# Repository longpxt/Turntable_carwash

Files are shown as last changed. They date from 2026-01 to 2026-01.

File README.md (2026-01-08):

infinity
model

# Turntable Car Wash (aka “Tron Car Wash”)

An open-hardware, industrial-scale in-bay car wash architecture that replaces the traditional moving overhead gantry with a **servo-driven turntable** and **parallel Spray Column modules**.

> Goal: increase throughput, simplify hose/cable routing, and improve maintainability by “inverting” the conventional in-bay design.

---
## OSHWA Certification

This project is **OSHWA Open Source Hardware Certified**.

- **OSHWA Certification ID:** **VN000001**
- Certification page: https://certification.oshwa.org/vn000001.html

---
## Context and motivation

Most in-bay automatic car washes rely on an overhead gantry that moves back-and-forth along the vehicle. While widely adopted, this approach tends to increase mechanical complexity and adds stress to **hose routing** and **cable management** due to constant motion and repeated travel paths.

This project explores a different architecture aimed at:
- reducing moving-axis complexity,
- enabling easier maintenance and modular expansion,
- improving process parallelism (multiple wash actions at once).

---

## The inverted architecture

**Turntable Car Wash** reverses the common approach:

- The **vehicle rotates** on a servo-driven turntable (angle-accurate rotation).
- The washing hardware is organized as **stationary modules** (Spray Columns) around the vehicle.
- By eliminating the moving gantry, **hose/cable runs can be shorter**, less twisted, and easier to service.

---

## Parallel washing modules (Spray Columns)

With the gantry eliminated, multiple **Spray Column** modules can work in parallel:
- Pre-soak, wash, rinse, wax, and spot-free can be distributed across modules.
- The system can reduce reliance on repeated serial gantry passes.
- Control logic focuses on *orchestrating parallel actions* and optimizing rotation timing.

---

## System structure

Key subsystems include:
- **Servo-driven turntable** for smooth, angle-accurate rotation
- **Spray Column modules** (modular washing columns)
- **PLC control** for deterministic motion + sequencing
- **Embedded PC software** 
- **Electrical system** integrating PLC, servo drive(s), pumps and sensors.
- **Industrial mechanical structure** designed for replication and serviceability (sheet metal/bolted assemblies)

---

## Repository layout

├─ Spray column/
│ └─ SolidWorks design files for the washing module (Spray Column)
├─ Turntable/
│ └─ SolidWorks design files for the servo-driven turntable
├─ Software & PLC/
│ ├─ PLC source code (control logic, sequencing, motion)
│ └─ Embedded PC software source code 
└─ Electrical/
└─ Electrical drawings for PLC, servo, pumps, and overall control system

---

## Prototype status and early observations

An MVP prototype with a single wash module has been built and tested. Early observations indicate that:
- The architecture is feasible for in-bay operation.
- Optimization of rotation + spray timing has a measurable impact on wash quality and resource usage.
- Long-term reliability will depend heavily on the turntable subsystem design (sealing, drainage, and protection in wet/chemical environments).

---

## Known engineering challenges / trade-offs

The **turntable** is the most demanding subsystem, with challenges including:
- long-life bearings and sealing in a wet, chemical environment,
- debris / grit intrusion protection,
- drainage and corrosion mitigation,
- mechanical rigidity under vehicle load,
- safety interlocks and fault handling for rotating machinery.

---

## Demonstration

Video demo: https://youtu.be/eL5WlzASyZ8

---

## Open release

This project is released as **open hardware** under the **CERN Open Hardware Licence (CERN-OHL-W)**.

- Hardware files: CAD (SolidWorks), electrical drawings
- Control: PLC code
- Software: embedded PC components

See the `LICENSE` file for the exact terms.

---

## Safety notice

This is an **industrial machine concept** involving electricity, rotating machinery, pressurized water, and chemicals.
You are responsible for ensuring compliance with local electrical/mechanical codes, safety guarding, E-stop strategy, interlocks, and chemical handling requirements before building or operating any derivative system.

---

## Contributing

Contributions are welcome:
- mechanical design improvements (turntable sealing/drainage, modularization)
- PLC sequencing and safety logic
- embedded software
- documentation (assembly, commissioning, maintenance)

---

## Author

**Long Phan** — inventor and R&D contractor working across mechanical design, automation, software, and IoT.
For questions, please contact: **longphan@ieee.org**

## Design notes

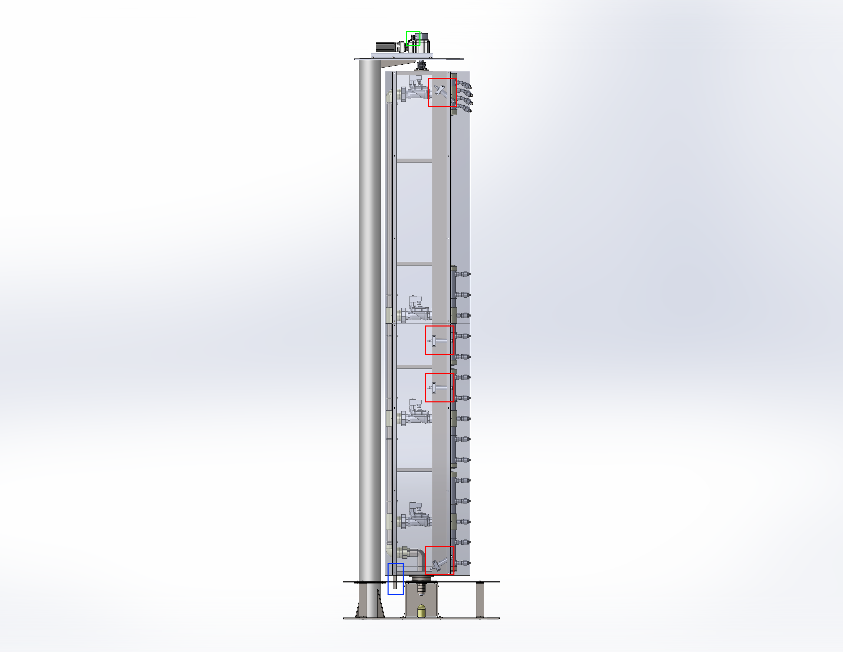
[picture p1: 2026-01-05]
Spray column/Images/2a.png

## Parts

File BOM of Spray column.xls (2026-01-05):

ITEM NO. | PART NUMBER | DESCRIPTION | QTY.
1 | C-pillar base mount |  | 1
2 | DN125 column |  | 1
3 | U-bracket rotary joint base |  | 1
4 | 22212 bearing flange |  | 1
5 | SKF_22212 E_ir_oh |  | 1
6 | SKF_22212 E_or_oh |  | 1
7 | SKF_22212 E_r1_oh |  | 19
8 | SKF_22212 E_r2_oh |  | 19
9 | 22212 bearing bottom flange |  | 1
10 | U-bracket rotary joint base cover |  | 2
11 | base reinforcement plate |  | 4
12 | upper spray-column alignment bar |  | 1
13 | gearbox-mount reinforcement |  | 1
14 | ground-cover base bracket |  | 5
15 | reinforced ground- cover base bracket |  | 5
16 | round-post ground- cover base bracket |  | 1
17 | ground surface cover |  | 1
18 | ground surface cover – right |  | 1
19 | Z22H gearbox support bracket |  | 1
20 | AFCZ22S_50M200S2_No ne__3_oh |  | 1
21 | AFCZ22S_50M200S2_No ne__5_oh |  | 1
22 | servo SGMAH- 04AAA41_vthtp3_oh | Yaskawa SGMAH- 04AAA41 or Mitsubishi MR-J3-40A | 1
23 | Z22 gearbox shaft |  | 1
24 | bowex_m24_1b |  | 1
25 | bowex_m24_3b |  | 1
26 | bowex_m24_2b |  | 1
27 | limit-switch jig |  | 1
28 | Z22 limit-switch shaft |  | 1
29 | V_155_1A5_BASE |  | 3
30 | V_155_1A5_ACTUATOR |  | 3
31 | DIN 912 M4 x 10 --- 10N |  | 4
32 | DIN 912 M6 x 10 --- 10N |  | 1
33 | DIN 912 M8 x 12 --- 12N |  | 10
34 | JIS B 1111 Binding head screw M3 x 35 -- 12N |  | 2
35 | DIN 912 M5 x 16 --- 16N |  | 36
36 | solenoid_valve_1b_3b_ oh |  | 4
37 | solenoid_valve_2b_3b_ 3b_oh |  | 4
38 | solenoid_valve_3b_3b_ 3b_oh |  | 4
39 | DN50 PPR water distribution pipe |  | 1
40 | DN50 PPR male-thread union |  | 8
41 | DN40-PN25 threaded flange |  | 2
42 | DN50 PPR tee |  | 7
43 | DN50 PPR female- thread straight connector |  | 1
44 | DN50 PPR elbow |  | 2
45 | DN50 PPR distributor pipe |  | 3
46 | DN50 PPR end cap |  | 8
47 | PPR weld in saddle 50–20 |  | 14
48 | PPR weld in saddle 75–20 |  | 5
49 | DN50 PPR coupling–distributor joint |  | 4
50 | Female Thread Reducer DN15-DN8 |  | 19
51 | PPR Female threaded coupling 20xDN15 |  | 15
52 | Spay MEG 1530 |  | 19
53 | upper DN50 PPR distributor |  | 1
54 | PPR Female threaded coupling 20xDN15 45deg |  | 4
55 | HD40R bod |  | 1
56 | HD40R base v3-3b |  | 1
57 | water supply pipe |  | 1
58 | DN40 male-female thread adapter |  | 1
59 | spray-pipe housing – base |  | 1
60 | spray-pipe housing – rear panel |  | 1
61 | spray-pipe housing – front panel |  | 1
62 | spray-pipe housing – cross bar |  | 4
63 | spray-pipe housing – cover |  | 1
64 | spray-pipe housing – pipe clamp |  | 8
65 | Top flange |  | 1
66 | foam-nozzle hose clamp |  | 1
67 | spray-pipe housing – main-nozzle locator |  | 1
68 | DIN 912 M8 x 20 --- 20N |  | 4
69 | DIN EN ISO 10511 - M8 - N |  | 4
70 | rear lower side cover |  | 1
71 | rear upper side cover |  | 1
72 | front lower side cover - left |  | 1
73 | front upper side cover - left |  | 1
74 | rear lower side cover - left |  | 1
75 | rear upper side cover - left |  | 1
76 | front lower side cover |  | 1
77 | front upper side cover |  | 1
78 | foam nozzle |  | 4
79 | foam-nozzle clamp |  | 8
80 | DIN 912 M6 x 50 --- 24N |  | 8
81 | DIN EN ISO 10511 - M6 - N |  | 8
82 | U bold |  | 7
83 | water-spray pipe cover – rear |  | 2
84 | water-spray pipe cover – side |  | 4
85 | water-spray pipe cover – front-upper (reversed) |  | 1
86 | water-spray pipe cover – front-lower (reversed) |  | 1
87 | front water-spray pipe jig |  | 1
88 | upper front water- spray pipe jig |  | 1

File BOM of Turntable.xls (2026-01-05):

ITEM NO. | PART NUMBER | DESCRIPTION | QTY.
1 | base support |  | 1
2 | upper bearing retainer ring |  | 1
3 | rotary hub cover |  | 1
4 | shaft of center hub |  | 1
5 | brass bushing 110 |  | 1
6 | 51224_bottom |  | 1
7 | 51224_middle |  | 1
8 | 51224_top |  | 1
9 | turntable flange plate |  | 1
10 | outer running track 60 |  | 6
11 | center-track connecting bar |  | 6
12 | inner running track 60 |  | 6
13 | inner-track connecting bar |  | 6
14 | linkage |  | 60
15 | ram base |  | 16
16 | top ram plate |  | 16
17 | ram support |  | 80
18 | upper cover plate center |  | 1
19 | 50-1 cross bar |  | 16
20 | 50-2 cross bar |  | 16
21 | distribution-bar 50x50 |  | 16
22 | PU51x17 |  | 32
23 | SKF 6003 |  | 64
24 | shaft 17x134 |  | 32
25 | wheel frame PU51x17 |  | 32
26 | turntable distribution- bar linkage |  | 16
27 | distribution-bar cover |  | 16
28 | M5-54 rack strip liner |  | 32
29 | 50-31 cross bar |  | 16
30 | 50-41 cross bar |  | 16
31 | support bar |  | 16
32 | M5-54 strip |  | 16
33 | bottom triangle linkage |  | 8
34 | top triangle linkage |  | 8
35 | triangle cover plate |  | 1
36 | WS120F grearbox | GTC | 1
37 | HC SFS 152 | Mitsubishi | 1
38 | gearbox gear |  | 1
39 | gearbox base |  | 1
40 | servo shaft 24 |  | 1
41 | gearbox housing |  | 1

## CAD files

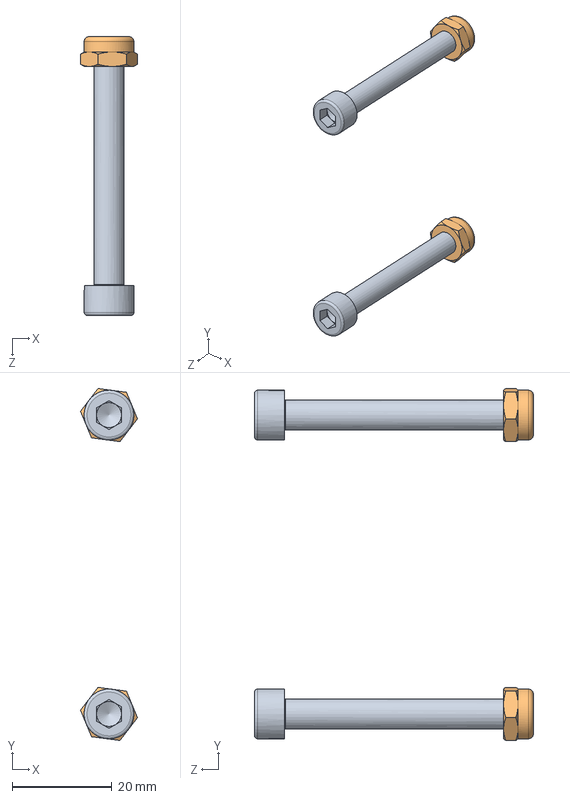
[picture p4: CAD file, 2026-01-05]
Spray column/Foam Nozzle Cluster Assembly.SLDASM
11.4 x 70.7 x 56.0 mm
socket head cap screw_din x 2
prevailing torque nut thin insert_din x 2

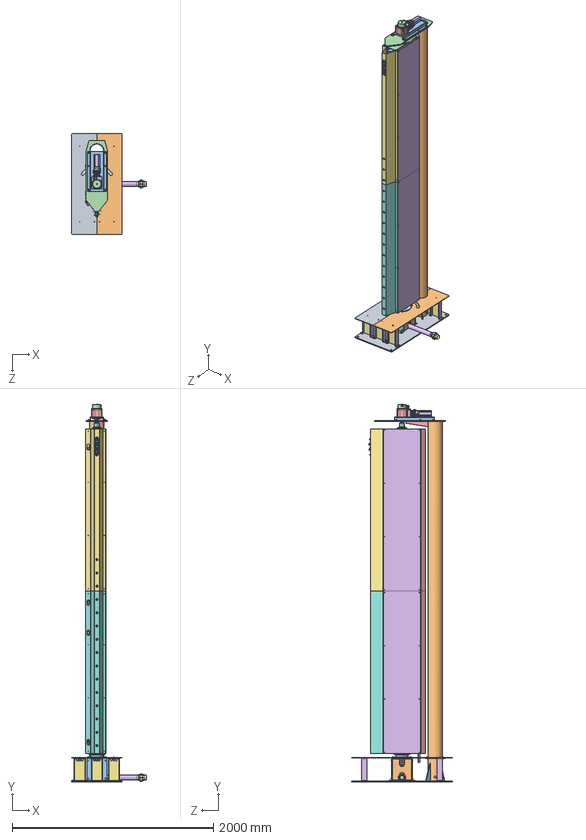
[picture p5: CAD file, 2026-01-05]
Spray column/Spray Column Assem.SLDASM
741.2 x 3755.0 x 1000.0 mm
C-pillar base mount
DN125 column
U-bracket rotary joint base
22212 bearing flange
SKF_22212 E_ir_oh
SKF_22212 E_or_oh
SKF_22212 E_r1_oh x 19
SKF_22212 E_r2_oh x 19
22212 bearing bottom flange
U-bracket rotary joint base cover x 2
base reinforcement plate x 4
upper spray-column alignment bar
gearbox-mount reinforcement
ground-cover base bracket x 5
reinforced ground-cover base bracket x 5
round-post ground-cover base bracket
ground surface cover
ground surface cover – right
Z22H gearbox support bracket
AFCZ22S_50M200S2_None__3_oh
AFCZ22S_50M200S2_None__5_oh
servo SGMAH-04AAA41_vthtp3_oh
Z22 gearbox shaft
bowex_m24_1b
bowex_m24_3b
bowex_m24_2b
limit-switch jig
Z22 limit-switch shaft
V_155_1A5_BASE x 3
V_155_1A5_ACTUATOR x 3
socket head cap screw_din x 63
cross recessed binding head screw_jis x 2
solenoid_valve_1b_3b_oh x 4
solenoid_valve_2b_3b_3b_oh x 4
solenoid_valve_3b_3b_3b_oh x 4
DN50 PPR water distribution pipe
DN50 PPR male-thread union x 8
DN40-PN25 threaded flange x 2
DN50 PPR tee x 7
DN50 PPR female-thread straight connector
DN50 PPR elbow x 2
DN50 PPR distributor pipe x 3
DN50 PPR end cap x 8
PPR weld in saddle 50–20 x 14
PPR weld in saddle 75–20 x 5
DN50 PPR coupling–distributor joint x 4
Female Thread Reducer DN15-DN8 x 19
PPR Female threaded coupling 20xDN15 x 15
Spay MEG 1530 x 19
upper DN50 PPR distributor
PPR Female threaded coupling 20xDN15 45deg x 4
HD40R bod
HD40R base v3-3b
water supply pipe
DN40 male-female thread adapter
spray-pipe housing – base
spray-pipe housing – rear panel
spray-pipe housing – front panel
spray-pipe housing – cross bar x 4
spray-pipe housing – cover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

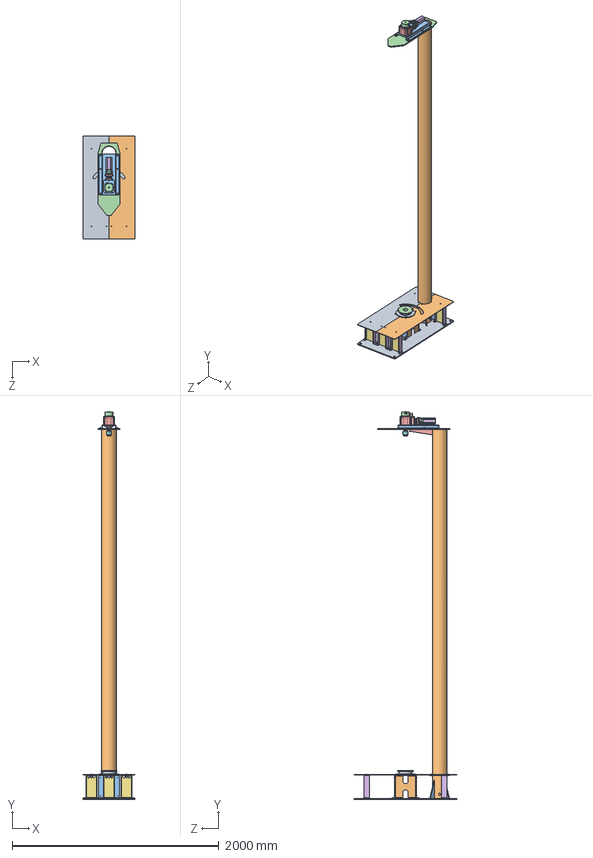
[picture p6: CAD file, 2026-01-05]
Spray column/C-Frame Base Assembly.SLDASM
500.0 x 3755.0 x 1000.0 mm
C-pillar base mount
DN125 column
U-bracket rotary joint base
22212 bearing flange
SKF_22212 E_ir_oh
SKF_22212 E_or_oh
SKF_22212 E_r1_oh x 19
SKF_22212 E_r2_oh x 19
22212 bearing bottom flange
U-bracket rotary joint base cover x 2
base reinforcement plate x 4
upper spray-column alignment bar
gearbox-mount reinforcement
ground-cover base bracket x 5
reinforced ground-cover base bracket x 5
round-post ground-cover base bracket
ground surface cover
ground surface cover – right
Z22H gearbox support bracket
AFCZ22S_50M200S2_None__3_oh
AFCZ22S_50M200S2_None__5_oh
servo SGMAH-04AAA41_vthtp3_oh
Z22 gearbox shaft
bowex_m24_1b
bowex_m24_3b
bowex_m24_2b
limit-switch jig
Z22 limit-switch shaft
socket head cap screw_din x 51
cross recessed binding head screw_jis x 2

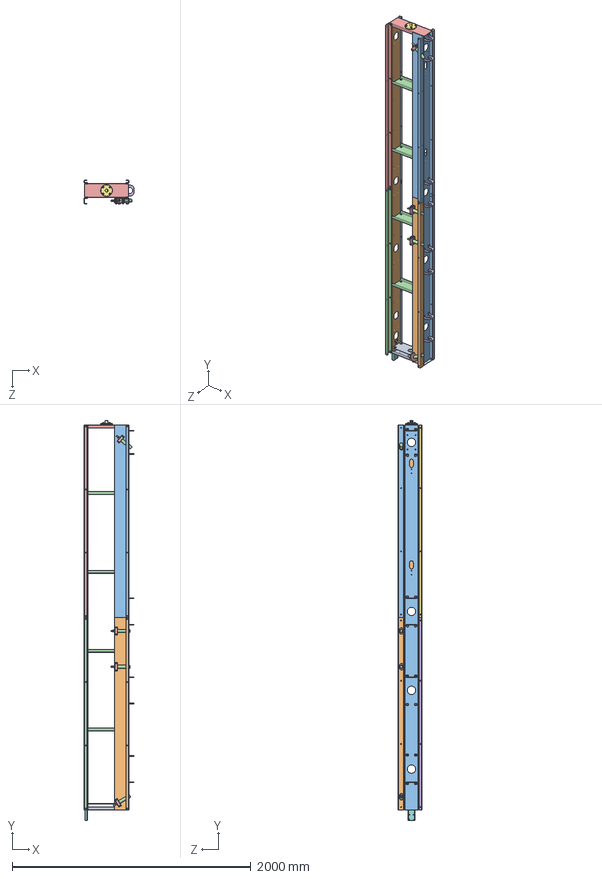
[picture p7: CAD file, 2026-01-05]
Spray column/Spray-Pipe Housing Assembly.SLDASM
417.0 x 3349.0 x 198.0 mm
spray-pipe housing – base
spray-pipe housing – rear panel
spray-pipe housing – front panel
spray-pipe housing – cross bar x 4
spray-pipe housing – cover
spray-pipe housing – pipe clamp x 8
Top flange
foam-nozzle hose clamp
spray-pipe housing – main-nozzle locator
socket head cap screw_din x 12
prevailing torque nut thin insert_din x 12
rear lower side cover
rear upper side cover
front lower side cover - left
front upper side cover - left
rear lower side cover - left
rear upper side cover - left
front lower side cover
front upper side cover
foam nozzle x 4
foam-nozzle clamp x 8

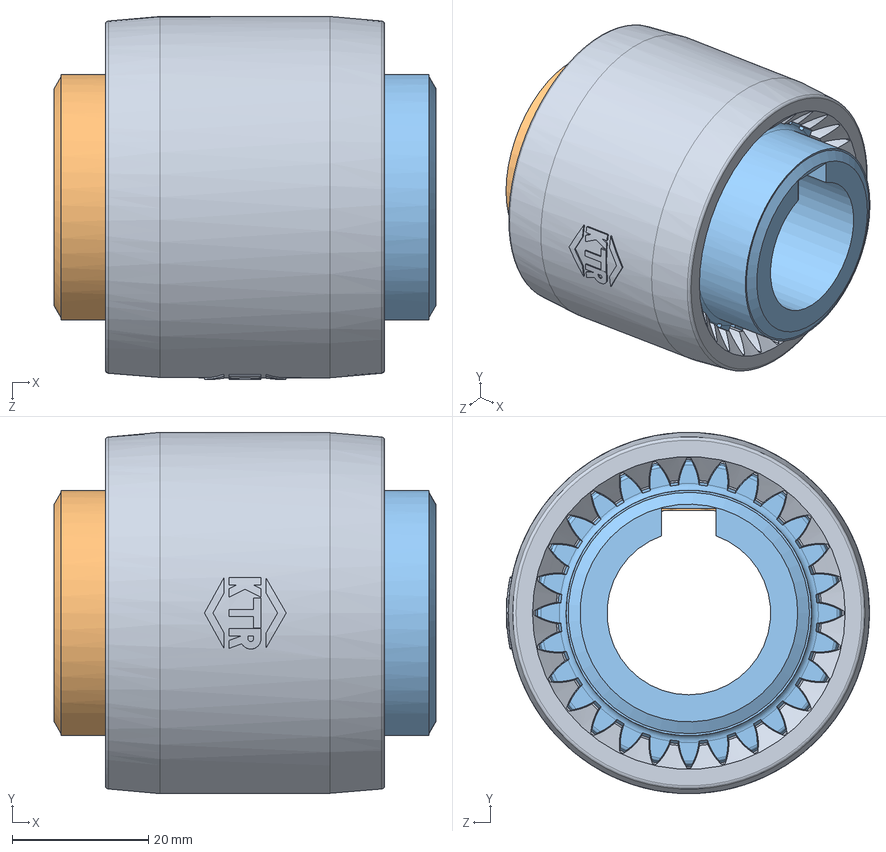
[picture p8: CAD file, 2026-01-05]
Spray column/bowex_m-24_c.SLDASM
56.0 x 53.0 x 53.2 mm
bowex_m24_1b
bowex_m24_3b
bowex_m24_2b

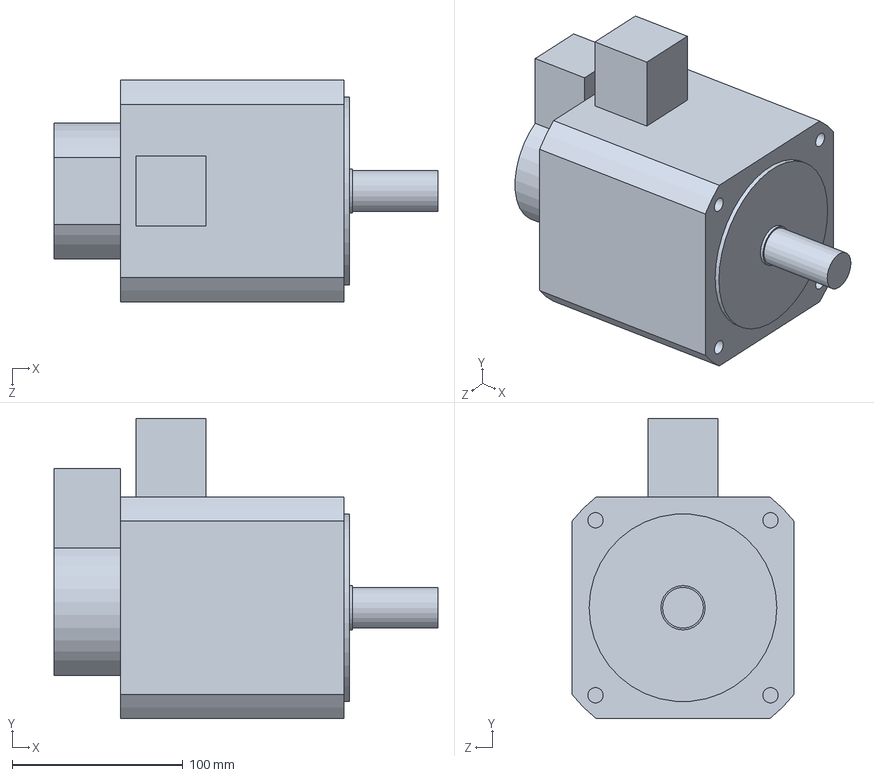
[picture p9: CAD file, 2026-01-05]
Turntable/assem WS120F - HC SFS152.SLDASM
225.0 x 176.0 x 130.0 mm

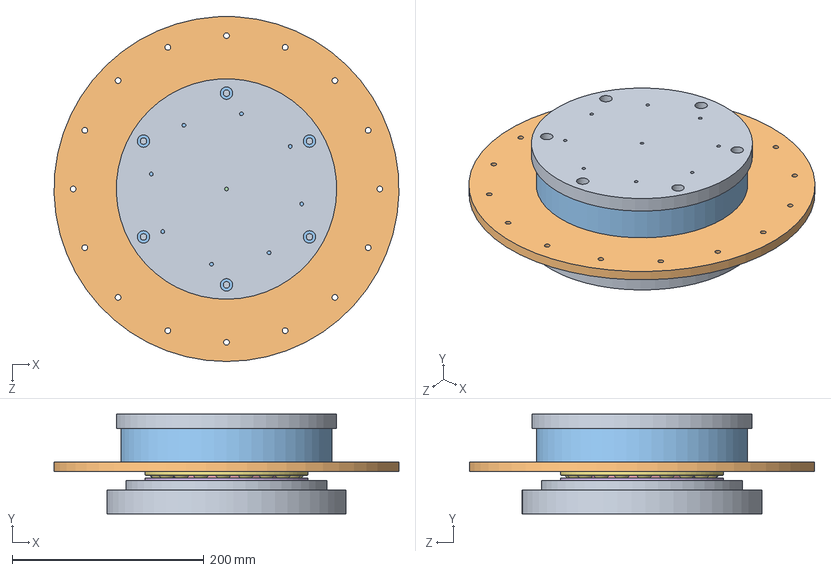
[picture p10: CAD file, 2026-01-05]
Turntable/assem center hub.SLDASM
359.8 x 104.0 x 360.0 mm
base support
upper bearing retainer ring
rotary hub cover
shaft of center hub
brass bushing 110
51224_bottom
51224_middle
51224_top

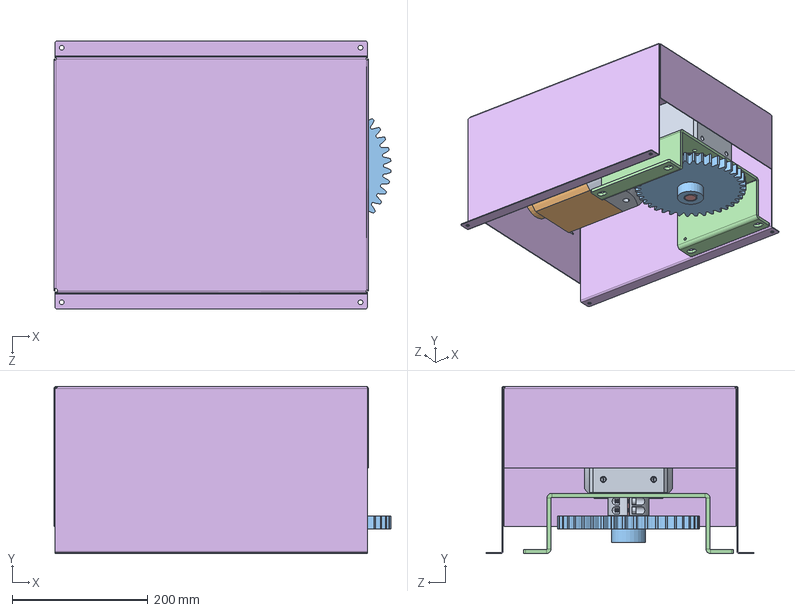
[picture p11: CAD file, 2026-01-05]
Turntable/assem gearbox.SLDASM
496.4 x 246.5 x 395.0 mm
WS120F grearbox
HC SFS 152
gearbox gear
gearbox base
servo shaft 24
gearbox housing

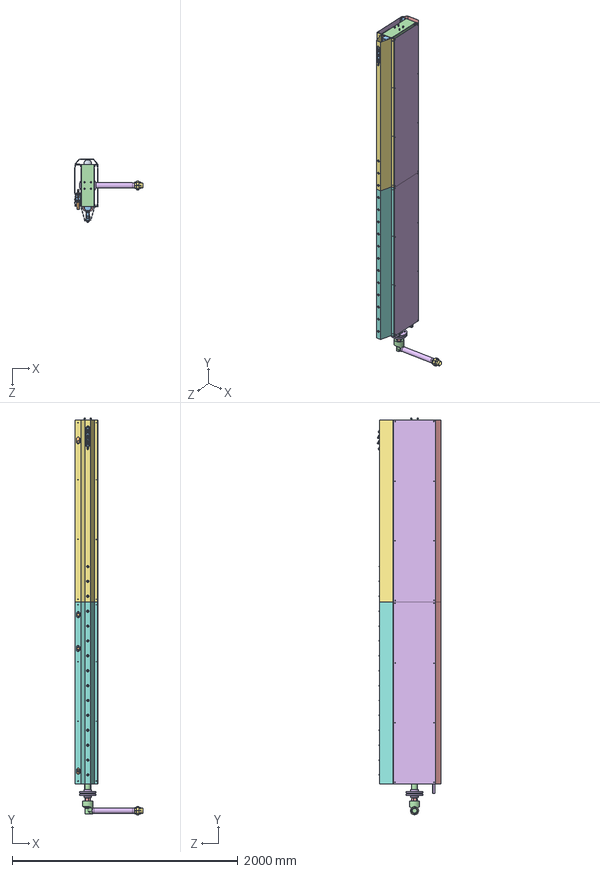
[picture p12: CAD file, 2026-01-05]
Spray column/Water Spray Pipe Assembly.SLDASM
606.2 x 3520.3 x 566.1 mm
solenoid_valve_1b_3b_oh x 4
solenoid_valve_2b_3b_3b_oh x 4
solenoid_valve_3b_3b_3b_oh x 4
DN50 PPR water distribution pipe
DN50 PPR male-thread union x 8
DN40-PN25 threaded flange x 2
DN50 PPR tee x 7
DN50 PPR female-thread straight connector
DN50 PPR elbow x 2
DN50 PPR distributor pipe x 3
DN50 PPR end cap x 8
PPR weld in saddle 50–20 x 14
PPR weld in saddle 75–20 x 5
DN50 PPR coupling–distributor joint x 4
Female Thread Reducer DN15-DN8 x 19
PPR Female threaded coupling 20xDN15 x 15
Spay MEG 1530 x 19
upper DN50 PPR distributor
PPR Female threaded coupling 20xDN15 45deg x 4
HD40R bod
HD40R base v3-3b
water supply pipe
DN40 male-female thread adapter
spray-pipe housing – base
spray-pipe housing – rear panel
spray-pipe housing – front panel
spray-pipe housing – cross bar x 4
spray-pipe housing – cover
spray-pipe housing – pipe clamp x 8
foam-nozzle hose clamp
spray-pipe housing – main-nozzle locator
socket head cap screw_din x 12
prevailing torque nut thin insert_din x 12
rear lower side cover
rear upper side cover
front lower side cover - left
front upper side cover - left
rear lower side cover - left
rear upper side cover - left
front lower side cover
front upper side cover
foam nozzle x 4
foam-nozzle clamp x 8
U bold x 7
water-spray pipe cover – rear x 2
water-spray pipe cover – side x 4
water-spray pipe cover – front-upper (reversed)
water-spray pipe cover – front-lower (reversed)

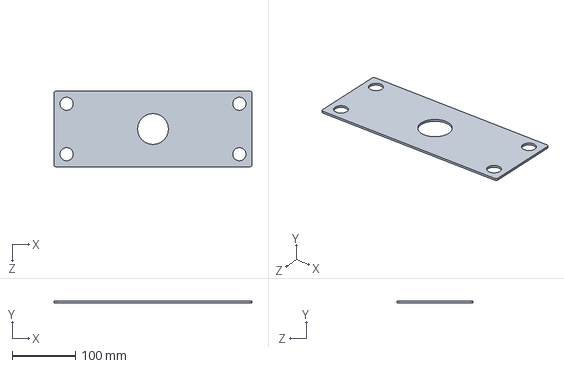
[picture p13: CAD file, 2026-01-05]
Spray column/spray-pipe housing – main-nozzle locator.SLDPRT
314.0 x 3.00 x 120.0 mm

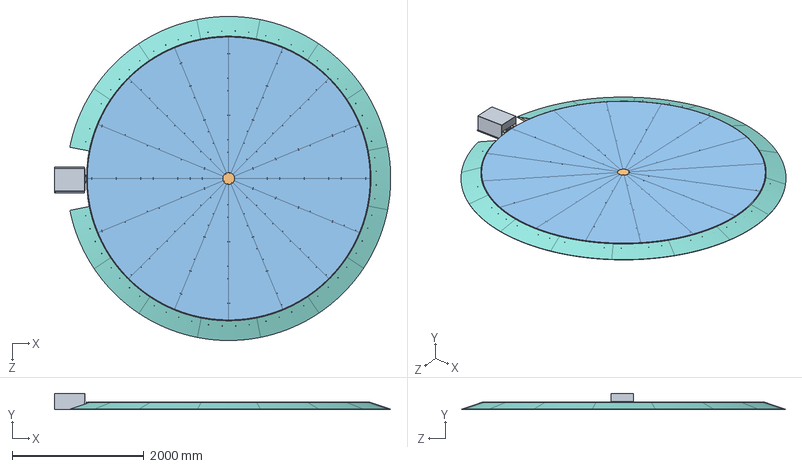
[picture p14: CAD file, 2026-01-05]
Turntable/Assem Turntable.SLDASM
5113.6 x 246.5 x 4924.9 mm
base support
upper bearing retainer ring
rotary hub cover
shaft of center hub
brass bushing 110
51224_bottom
51224_middle
51224_top
turntable flange plate
outer running track 60 x 6
center-track connecting bar x 6
inner running track 60 x 6
inner-track connecting bar x 6
linkage x 60
ram base x 15
top ram plate x 15
ram support x 75
upper cover plate center
50-1 cross bar x 16
50-2 cross bar x 16
distribution-bar 50x50 x 16
PU51x17 x 32
SKF 6003 x 64
shaft 17x134 x 32
wheel frame PU51x17 x 32
turntable distribution-bar linkage x 16
distribution-bar cover x 16
M5-54 rack strip liner x 32
50-31 cross bar x 16
50-41 cross bar x 16
support bar x 16
M5-54 strip x 16
bottom triangle linkage x 8
top triangle linkage x 8
triangle cover plate x 16
WS120F grearbox
HC SFS 152
gearbox gear
gearbox base
servo shaft 24
gearbox housing

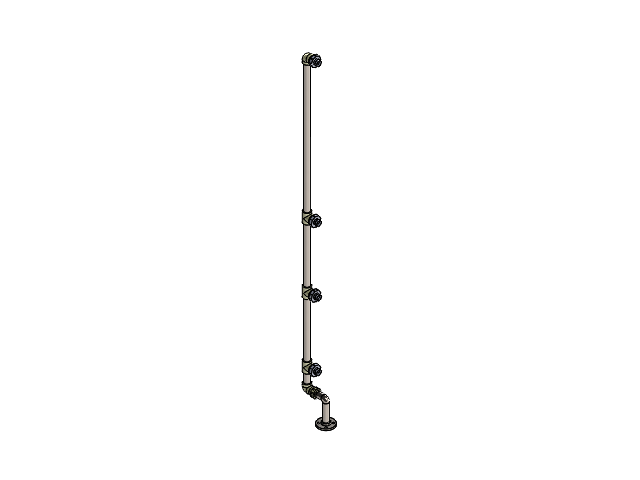
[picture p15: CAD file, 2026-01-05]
Spray column/DN40 Stainless-Steel Water Distributor Assembly.SLDASM
DN50 PPR water distribution pipe
DN50 PPR male-thread union x 4
DN40-PN25 threaded flange
DN50 PPR tee x 3
DN50 PPR female-thread straight connector
DN50 PPR elbow x 2

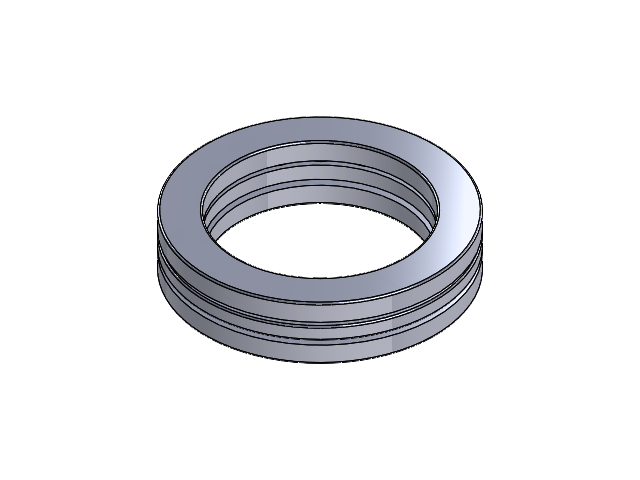
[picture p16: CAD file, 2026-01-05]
Turntable/SKF 51224.SLDASM
51224_bottom
51224_middle
51224_top

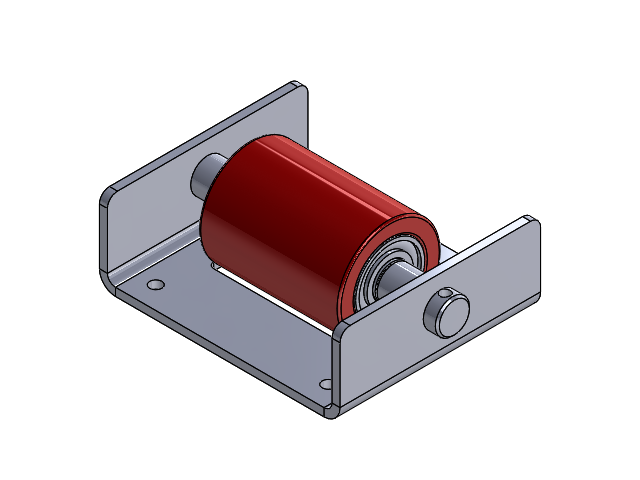
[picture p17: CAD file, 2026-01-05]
Turntable/Wheel assem PU51x17.SLDASM
PU51x17_oh
SKF 6003_simple_oh x 2
truc 17x134_oh
cang banh xe PU51x17 v4.1_oh

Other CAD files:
Turntable/assem ram.SLDASM
Turntable/assem triangle 50.SLDASM
Turntable/assem distribution-bar.SLDASM
Turntable/assem running track.SLDASM
Spray column/22212 Bearing Flange Assembly.SLDASM
Spray column/22212 bearing bottom flange.SLDPRT
Spray column/22212 bearing flange.SLDPRT
Spray column/AFCZ22S_50M200S2_None__3_oh.SLDPRT
Spray column/AFCZ22S_50M200S2_None__5_oh.SLDPRT
Spray column/AFCZ22S_50M200S2_None__oh.SLDASM
Spray column/C-pillar base mount.SLDPRT
Spray column/DN125 column.SLDPRT
Spray column/DN40 male-female thread adapter.SLDPRT
Spray column/DN40-PN25 threaded flange.SLDPRT
Spray column/DN50 PPR Distribution Pipe Assembly – Upper.SLDASM
Spray column/DN50 PPR Distribution Pipe Assembly.SLDASM
Spray column/DN50 PPR coupling–distributor joint.SLDPRT
Spray column/DN50 PPR distributor pipe.SLDPRT
Spray column/DN50 PPR elbow.SLDPRT
Spray column/DN50 PPR end cap.SLDPRT
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

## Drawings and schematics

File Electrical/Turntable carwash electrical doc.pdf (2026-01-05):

REV. | NAME DATE

# CONTRACT :

# CHANGES

# SCHEME

# REVISION

01

0

# longphan@ieee.org

# Long Phan Open Hardware Community

# Turntable carwash

# Document book

0 | 12/2/2025 | long

Document book | REVISION 0 Long Phan SCHEME

## Main electrical closet LOCATION: CONTRACT:

0 | 12/2/2025 | long
REV. | | NAME DATE | CHANGES
| | 02 +L1

## 1-Document book

Drawing | Description | Function | Location | Revision | Date | Created by | Folder | Folder description
01 | Cover page | =F1 | +L1 | 0 | 12/2/2025 | long
02 | Drawings list | =F1 | +L1 | 0 | 12/2/2025 | long
03 | Single Line | =F1 | +L1 | 0 | 12/2/2025 | long
04 | Power | =F1 | +L1 | 0 | 12/29/2025 | long
05 | QD75D4 control | =F1 | +L1 | 0 | 1/2/2026 | long
06 | QX and QY control | =F1 | +L1 | 0 | 1/2/2026 | long
07 | Bill Of Materials grouped by manufacturer | =F1 | +L1 | 0 | 1/4/2026 | long
08 | Bill Of Materials grouped by manufacturer | =F1 | +L1 | 0 | 1/4/2026 | long

-CB1

-Q1

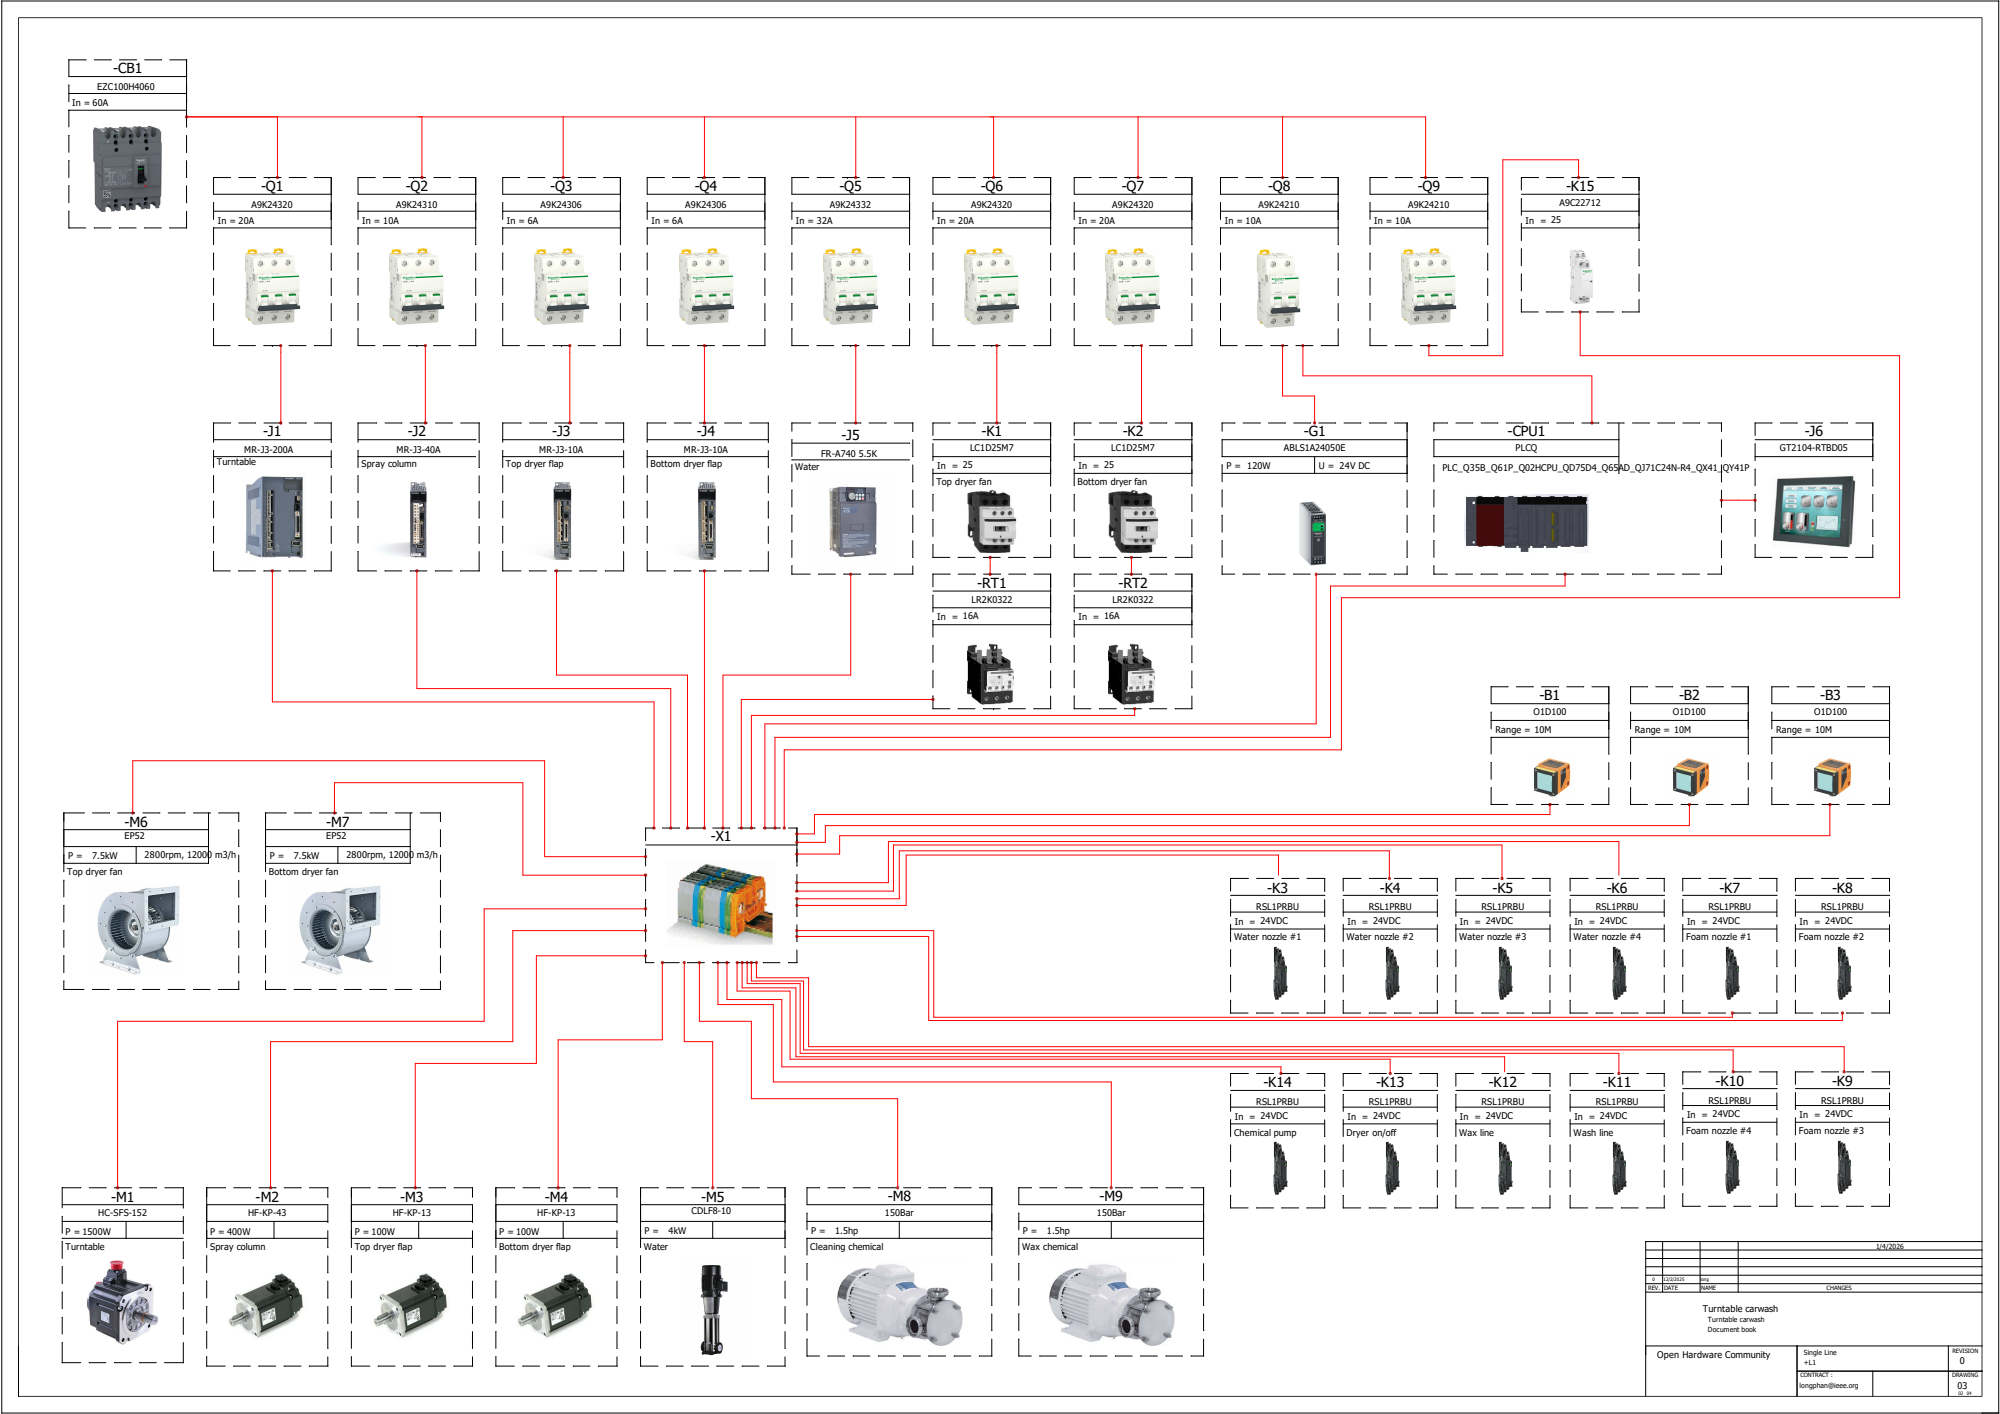
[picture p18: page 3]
DATEREV.; NAME; CHANGES; DRAWING; REVISION 0; long; Turntable carwash; Single Line; Document book; EZC100H4060; Turntable; Spray column; HC-SFS-152; Water; CDLF8-10; Top dryer fan; Bottom dryer fan; 2800rpm, 12000 m3/h; ABLS1A24050E; -CPU1; PLC_Q35B_Q61P_Q02HCPU_QD75D4_Q65AD_QJ71C24N-R4_QX41_QY41P; PLCQ; Range = 10M; 150Bar; Cleaning chemical; RSL1PRBU; Water nozzle #1; 24VDC; Water nozzle #2; Water nozzle #3; Water nozzle #4; Foam nozzle #1; Wax chemical; Foam nozzle #2; GT2104-RTBD05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

Top dryer flap

Bottom dryer flap

Top dryer fan

Bottom dryer fan

RSL1PRBU
Dryer on/off

Open Hardware Community

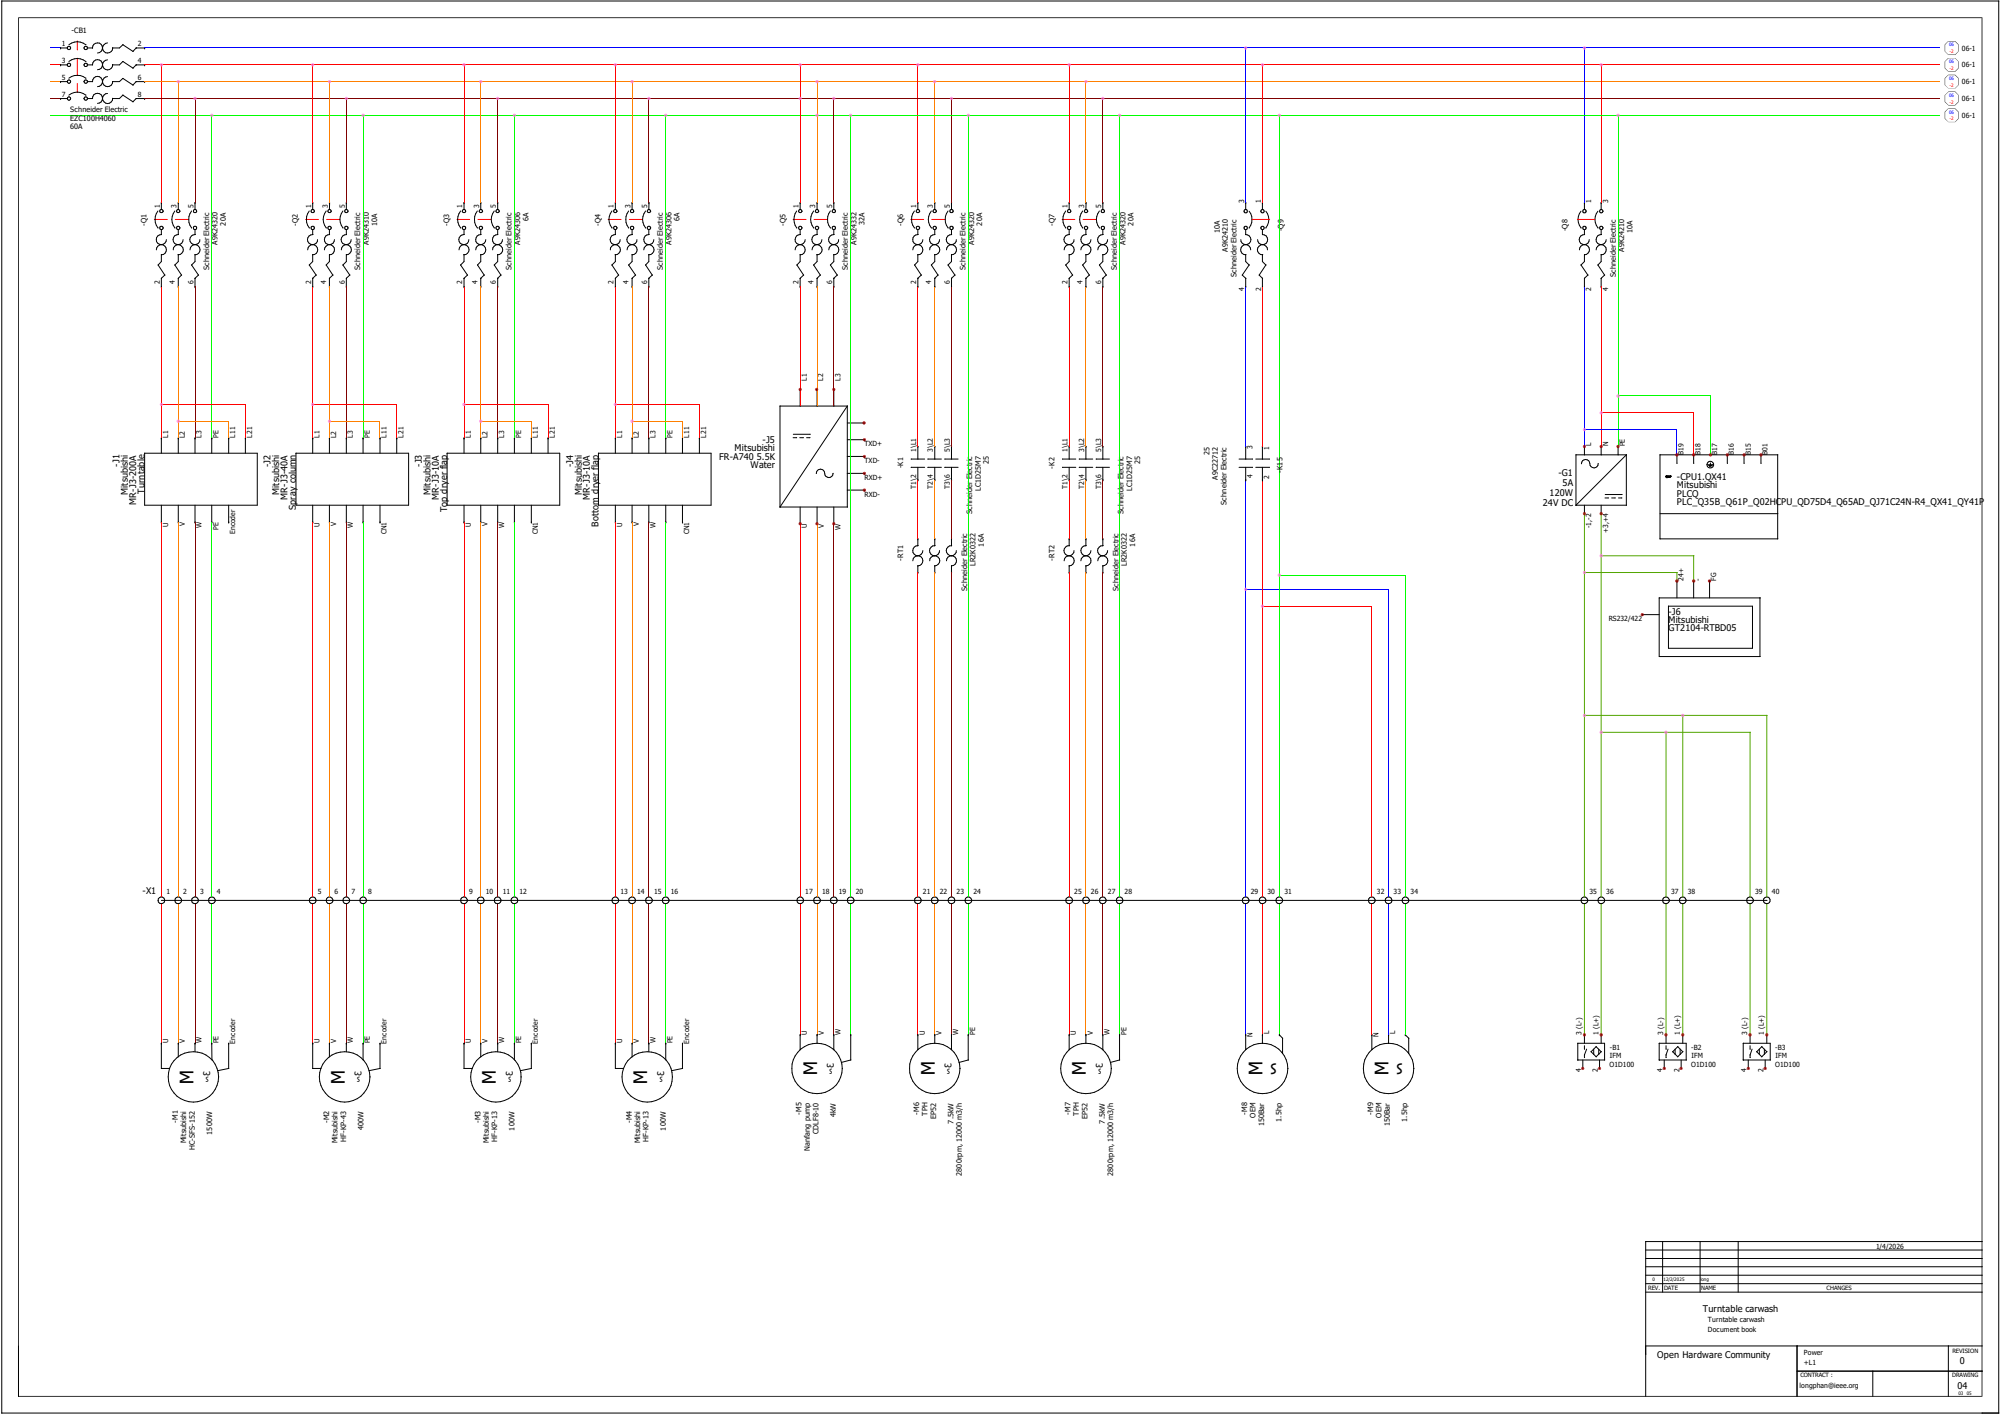
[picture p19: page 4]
DATEREV.; NAME; CHANGES; long; Power; Schneider Electric; UVW; Encoder; -J1 Mitsubishi MR-J3-200A; Turntable; Mitsubishi MR-J3-40A; Spray column; -J3 Mitsubishi MR-J3-10A; Mitsubishi MR-J3-10A; HC-SFS-152; Mitsubishi; -J5 Mitsubishi FR-A740 5.5K Water; TXD+; TXD-; RXD+; RXD-; CDLF8-10; Nanfang pump; 2800rpm, 12000 m3/h; TPH; -CPU1.QX41 Mitsubishi; PLCQ PLC_Q35B_Q61P_Q02HCPU_QD75D4_Q65AD_QJ71C24N-R4_QX41_QY41P; -J6 Mitsubishi GT2104-RTBD05; 150Bar; OEM; -B1 IFM O1D100; -B2 IFM O1D100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

Top dryer flap

Bottom dryer flap

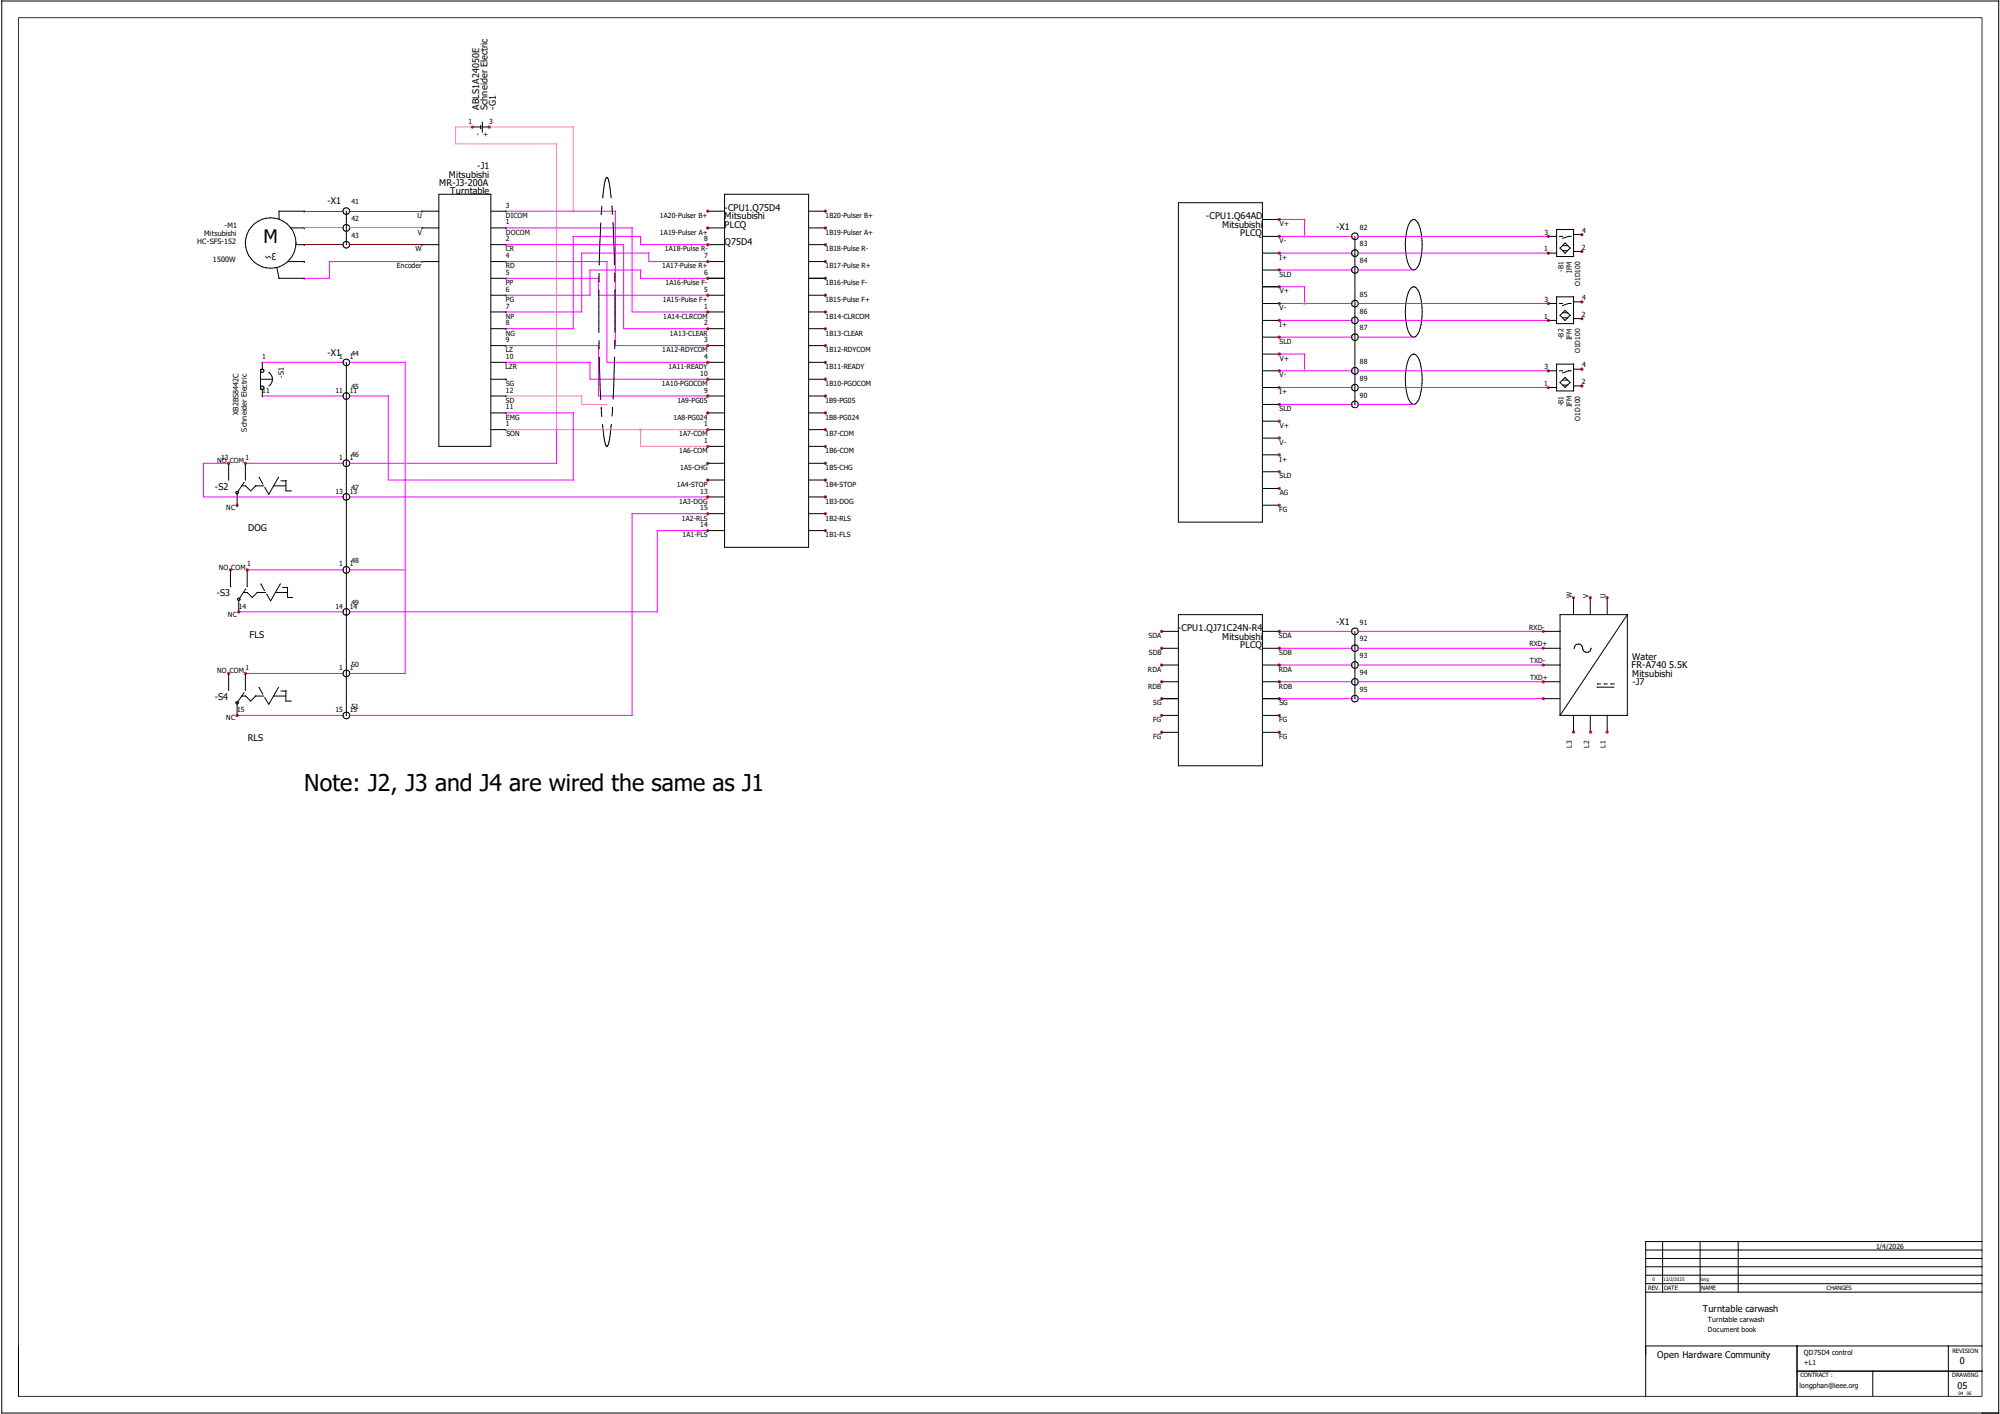
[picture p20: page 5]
DATEREV.; NAME; CHANGES; long; QD75D4 control; 1A20-Pulser B+; 1A19-Pulser A+; 1A18-Pulse R-; 1A17-Pulse R+; 1A16-Pulse F-; 1A15-Pulse F+; 1A14-CLRCOM; 1A13-CLEAR; 1A12-RDYCOM; 1A11-READY; 1A10-PGOCOM; 1A6-COM; 1A5-CHG; 1A4-STOP; 1A3-DOG; 1A2-RLS; 1A1-FLS; 1B20-Pulser B+; 1B19-Pulser A+; 1B18-Pulse R-; 1B17-Pulse R+; 1B16-Pulse F-; 1B15-Pulse F+; 1B14-CLRCOM; 1B13-CLEAR; 1B12-RDYCOM; 1B11-READY; 1B10-PGOCOM; 1B7-COM; 1B6-COM; 1B5-CHG; 1B4-STOP; 1B3-DOG; 1B2-RLS; 1B1-FLS; -CPU1.Q75D4 Mitsubishi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

U 42 | DICOM 1

43 V | DOCOM 2

EMG 1

1A7-COM 1

SDA | 92 RXD+

SDB | 93 TXD-

RDA | 94 TXD+

RDB | 95

RLS
Note: J2, J3 and J4 are wired the same as J1

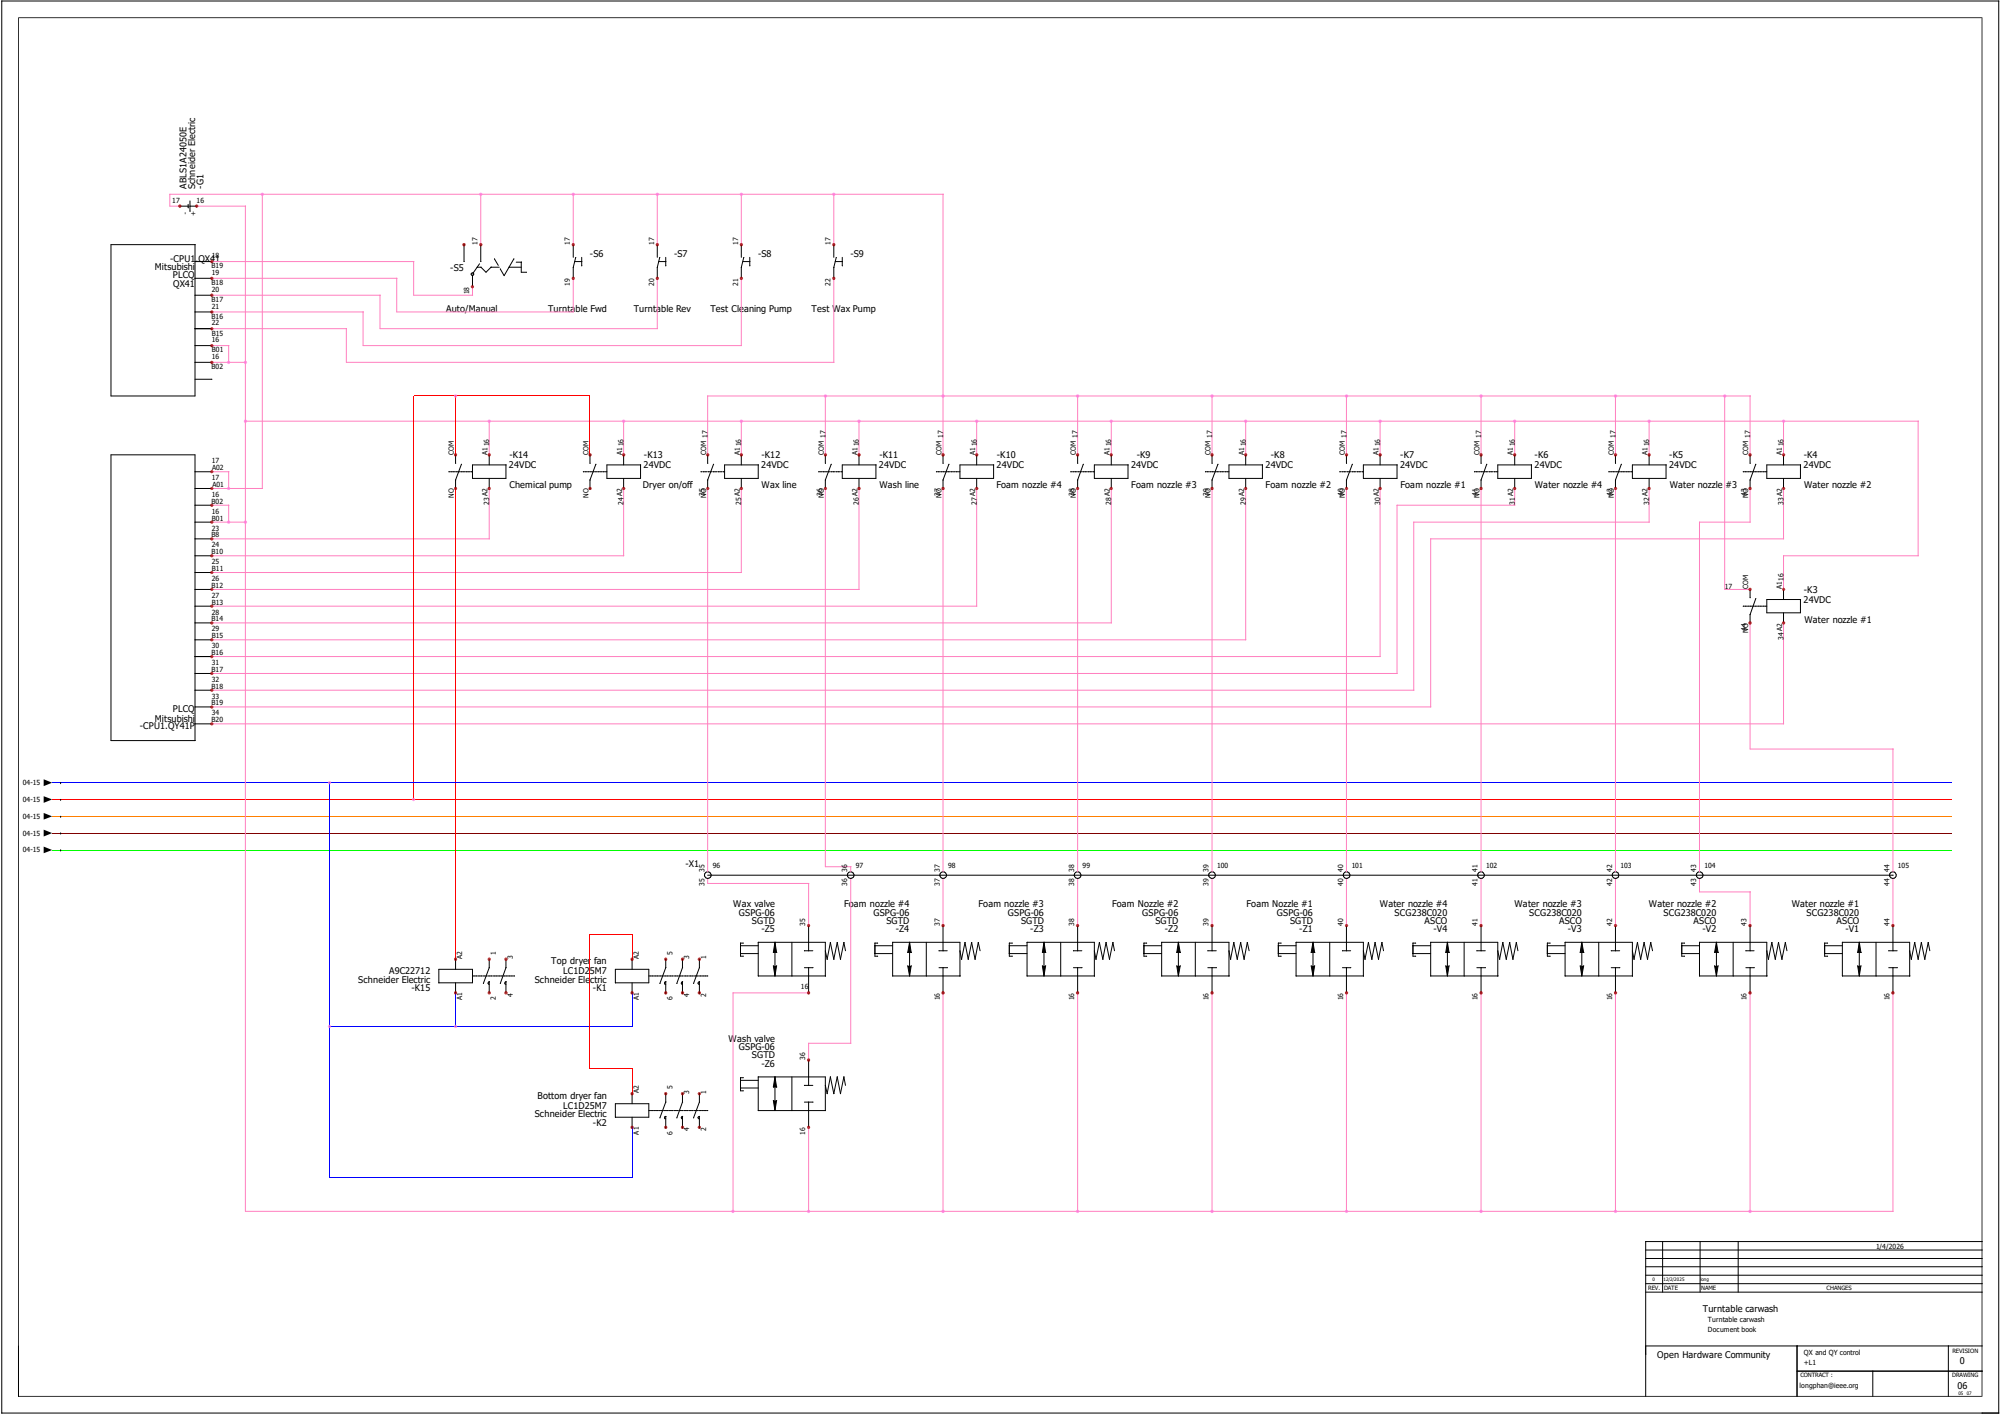
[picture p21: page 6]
DATEREV.; NAME; CHANGES; long; -CPU1.QY41P Mitsubishi; PLCQ; -CPU1.QX41 Mitsubishi; ABLS1A24050E; Schneider Electric; Auto/Manual; Turntable Fwd; Turntable Rev; -K14 24VDC; Chemical pump; COM NO; -K3 24VDC; Water nozzle #1; A1 A2 -K15 Schneider Electric A9C22712; SGTD; GSPG-06; Wax valve; Wash valve; Foam nozzle #4; Foam nozzle #3; Foam Nozzle #2; Foam Nozzle #1; ASCO; SCG238C020; Water nozzle #4; Water nozzle #3; Water nozzle #2

Test Cleaning Pump

Test Wax Pump

COM NO -K13 24VDC Dryer on/off

COM NO -K12 24VDC Wax line

COM NO -K11 24VDC Wash line

COM NO -K10 24VDC Foam nozzle #4

COM NO -K9 24VDC Foam nozzle #3

COM NO -K8 24VDC Foam nozzle #2

COM NO -K7 24VDC Foam nozzle #1

COM NO -K6 24VDC Water nozzle #4

COM NO -K5 24VDC Water nozzle #3

COM NO -K4 24VDC Water nozzle #2

A1 A2 -K1 Schneider Electric LC1D25M7 Top dryer fan

A1 A2 -K2 Schneider Electric LC1D25M7 Bottom dryer fan

QX and QY control

Document book | REVISION 0 Long Phan SCHEME

## Main electrical closet LOCATION: CONTRACT:

0 | 1/4/2026 | long
REV. | | NAME DATE | CHANGES
| | 07 +L1

## ASCO

| Reference | Mark | Description | Quantity
1 | SCG238C020 | -V1, -V2, -V3, -V4 | ASCO G1 1/2 Solenoid Valves | 4

## IFM

| Reference | Mark | Description | Quantity
1 | O1D100 | -B1, -B2, -B3 | Laser distance sensor | 3
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

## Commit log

2026-01-05 spray column design final
    [22212 Bearing Flange Assembly.SLDASM, 22212 bearing bottom flange.SLDPRT, 22212 bearing flange.SLDPRT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]
2026-01-05 Turntable design final
    [50-1 cross bar.SLDPRT, 50-2 cross bar.SLDPRT, 50-31 cross bar.SLDPRT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]
2026-01-05 Revise README with comprehensive project details
    Expanded the README to provide detailed information about the Turntable Car Wash project, including context, architecture, system structure, prototype status, engineering challenges, and safety notic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
